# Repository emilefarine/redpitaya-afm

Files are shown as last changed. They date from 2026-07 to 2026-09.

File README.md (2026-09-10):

# Open-Source Zynq-Based AFM Acquisition System

An open, low-cost acquisition instrument for Atomic Force Microscopy (AFM), built around the
[Red Pitaya STEMlab 125-14](https://redpitaya.com/) (Xilinx Zynq-7010 SoC) and delivered as a
self-contained 19-inch rack unit. It replaces the closed, expensive and proprietary acquisition
boards typically used in AFM setups with a fully inspectable and extensible signal chain.

The instrument generates an excitation signal, conditions it through a custom analog board,
drives the AFM, acquires the cantilever response, and processes it (FFT, peak detection,
lock-in detection) entirely on the device. Results are exposed over the network through an
SCPI-inspired protocol and can be driven from Python, LabVIEW, MATLAB or any TCP client.

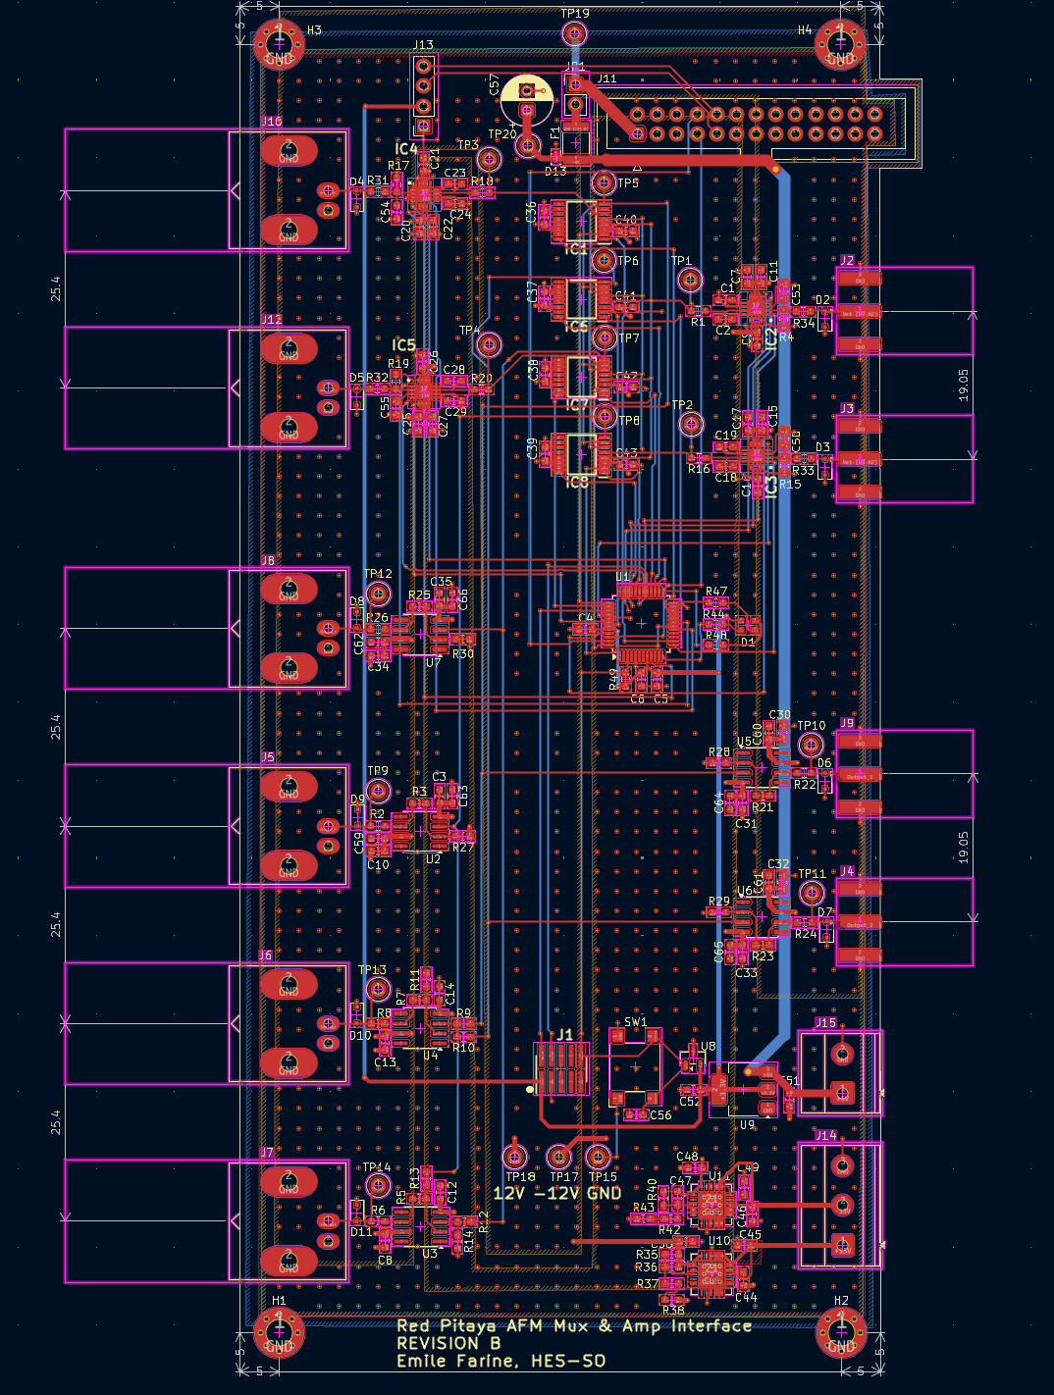
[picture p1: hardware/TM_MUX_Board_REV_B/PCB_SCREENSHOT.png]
MUX board


## Architecture

The system is organised in four layers:

| Layer | Description | Location |
|---|---|---|
| **FPGA datapath** | Custom programmable-logic design on the Zynq: excitation generation and acquisition around a single shared BRAM, with adaptive decimation | [`fpga/`](fpga/) |
| **Analog board** | Custom conditioning board: programmable gain (×1/8 to ×16), input multiplexer, ±10 V range, analog sum/difference outputs, LPC1114 control microcontroller, OLED IP display | [`hardware/`](hardware/), [`ElectronicBoard/`](ElectronicBoard/) |
| **Embedded C++ server** | Single-client TCP server running on the Red Pitaya's Linux, exposing an SCPI-inspired command language over the network | [`cpp/`](cpp/) |
| **Python clients** | Client library, interactive CLI, PyQt6 desktop GUI with routing schematic dialog, and deployment tooling | [`python/`](python/) |

Two measurement modes are available: a **broadband sinc** that captures a whole spectrum in a
few milliseconds, and a **lock-in sweep** that resolves narrow resonances.

### Repository layout

```
cpp/                 Embedded C++ server + signal processing (build & run on the Red Pitaya)
  Hardware/          Hardware abstraction: FPGA register access, board UART, SSD1306 OLED
  Server/            TCP server, SCPI command handler, protocol
  SignalProcessing/  Signal generation, FFT (FFTW3), resonance analysis
  Tools/             oled-ip helper + systemd service
  tests/             Host-side unit tests (run on the dev PC, no Red Pitaya needed)
python/              Client library, CLI, GUI (with routing schematic dialog) and deployment
fpga/
  rtl/               SystemVerilog / VHDL sources for the custom datapath
  bitfiles/          Prebuilt bitstream (flash without rebuilding in Vivado)
ElectronicBoard/
  src/               LPC1114 firmware for the analog board (MUX + gain control)
hardware/
  TM_MUX_Board_REV_B/  KiCad 10 project: schematics, PCB, 3D model, interactive BOM
```

## Requirements

### Hardware
- Red Pitaya STEMlab 125-14 (Zynq-7010)
- Custom analog MUX board (optional; design in [`hardware/`](hardware/)). Without it the
  server runs in Red Pitaya-only mode and the `BOARD:*` commands are unavailable.

### Software
- **Client PC:** Python **3.10+** (developed on 3.13)
- **On the Red Pitaya:** `g++` (C++17), FFTW3 single precision (`libfftw3f`), Red Pitaya
  libraries (`librp`, `librp-hw`, `librp-hw-calib`, `librp-hw-profiles`), all present on
  the stock Red Pitaya OS 2.0+ image
- **FPGA rebuilds only:** Xilinx Vivado/Vitis (a prebuilt bitstream is shipped, so this is
  optional)
- **Board firmware only:** MCUXpresso IDE + a J-Link EDU mini

## Installation

```bash
git clone https://github.com/emilefarine/redpitaya-afm 
cd redpitaya-afm
python -m venv .venv
# Windows:  .venv\Scripts\activate.bat
# Linux/macOS:  source .venv/bin/activate
pip install -r python/requirements.txt
```

All scripts that connect to the board accept `--host <ip>` (or the `RP_HOST` environment
variable). SSH credentials default to the Red Pitaya factory login `root` / `root` and can be
overridden with `--user` / `--password` (or `RP_USER` / `RP_PASSWORD`).

## Usage

### 1. Flash the FPGA bitstream

A prebuilt bitstream is included, so you do not need Vivado:

```bash
python python/rp_deploy.py --host 192.168.1.100 --deploy
python python/rp_deploy.py --host 192.168.1.100 --status   # expect: FPGA state operating
```

By default the newest `fpga/bitfiles/*.bit.bin` is used; pass `--bitfile <path>` to select
another. A raw `.bit` (from a local Vivado build) is converted automatically with `bootgen`
(point to it with `--bootgen` / the `BOOTGEN` env var, or let the script scan a local Vitis
install).

### 2. Build and deploy the C++ server

The C++ code is compiled **on the Red Pitaya** (not cross-compiled). `rp_deploy.py` mirrors
the sources over SSH, then build with `make`:

```bash
python python/rp_deploy.py --host 192.168.1.100 --cpp      # sync sources to the board

# then over SSH on the Red Pitaya, from the synced cpp/ directory:
make server        # build the AFM SCPI server
./out/afm_server   # run it (listens on TCP 5025)
```

Other `make` targets: `make all` (server + tools), `make tools`.

Host-side unit tests run on the dev PC without a Red Pitaya. Shell: the MSYS2 UCRT64
shell on Windows (install `mingw-w64-ucrt-x86_64-gtest` and `mingw-w64-ucrt-x86_64-fftw`
via pacman) or any POSIX shell on Linux (`apt install libgtest-dev libgmock-dev
libfftw3-dev`), plus `pip install gcovr` for coverage. From `cpp/`:

```bash
make test_host      # build and run the unit tests
make coverage       # unit tests + HTML report at out/host/coverage/index.html
```

### 3. Red Pitaya-only operation (no analog board)

The custom analog board is optional. To run measurements with only a Red Pitaya, start the
server with `--no-board`, the electronic board is then never probed and every `BOARD:*`
command is rejected with `ERR_HARDWARE: Electronic board disabled (RP-only mode)`:

```bash
./out/afm_server --no-board
```

Connect the cantilever signal directly to **IN1**, the only input acquired by the FPGA
datapath. `MEASURE:SINC` and `MEASURE:SWEEP` work exactly as with the board, mux routing
and programmable gain are unavailable. Query the active mode with `SYSTEM:MODE?` (`FULL`
or `RP_ONLY`); `SYSTEM:STATUS?` also reports `MODE=`. The GUI disables the board panel and
the routing schematic automatically in RP-only mode.

### 4. Connect a client

Interactive CLI:

```bash
python python/afm_cli.py 192.168.1.100
```

Desktop GUI (PyQt6, real-time magnitude/phase plots):

```bash
python python/afm_gui.py
```

The GUI has an "Open Routing Schematic" button showing the live 4x4 crossbar
routing and PGA gains (read from `BOARD:STATUS?`); the same dialog runs
standalone without hardware for preview:

```bash
python python/afm_schematic.py
```

Python library:

```python
from afm_client import AFMClient

with AFMClient("192.168.1.100") as client:
    client.init()
    spectrum = client.measure_sinc(center_kHz=1000, bandwidth_kHz=200)
    peak = spectrum.freq_kHz[spectrum.magnitude.argmax()]
    print(f"Peak at {peak:.1f} kHz")

    sweep = client.measure_sweep(center_kHz=1000, range_kHz=100, step_kHz=0.5)
```

## SCPI protocol

The server speaks an SCPI-inspired ASCII protocol over **TCP port 5025**. Commands are
case-insensitive, colon-separated, `?`-suffixed for queries, with comma-separated arguments;
every line ends with `\n`. Responses are a single line: `OK [data]` or `ERR_<CODE>: <message>`.

| Command | Description |
|---|---|
| `*IDN?` / `*RST` / `*OPC?` | IEEE 488.2 common commands |
| `SYSTEM:INIT` / `SYSTEM:DEINIT` / `SYSTEM:STATUS?` | Hardware lifecycle and status |
| `SYSTEM:PING` / `SYSTEM:VERSION?` / `SYSTEM:SHUTDOWN` | Connectivity check, server version, server shutdown |
| `SYSTEM:MODE?` | Operating mode: `FULL` or `RP_ONLY` (board disabled with `--no-board`) |
| `BOARD:MUX:ROUTE <out>,<in>` | Route input to output (channels 1-4) |
| `BOARD:MUX:DISCONNECT <out>` | Disconnect a multiplexer output |
| `BOARD:GAIN <ch>,<idx>` | Set programmable gain (idx 0-7 → ×1/8 … ×16) |
| `BOARD:STATUS?` / `BOARD:RESET` | Query board routing/gains, reset board to defaults |
| `MEASURE:SINC <center_kHz>,<bw_kHz>[,<samples>,<dec>,<amp>]` | Broadband sinc + FFT |
| `MEASURE:SWEEP <center_kHz>,<range_kHz>[,<step_kHz>,<dec>,<amp>]` | Lock-in frequency sweep |

`MEASURE:*` return a multi-line spectrum: a header `OK DATA <N> <BYTES>` followed by `N` rows of
`freq_kHz,magnitude,phase_rad`. `<BYTES>` is the exact size of the payload that follows the
header line, so a client can read it in one shot instead of scanning for newlines.

## MUX board firmware

The analog board is controlled by an on-board **LPC1114** microcontroller (MUX routing,
programmable gain, OLED IP display). Firmware sources are in [`ElectronicBoard/src/`](ElectronicBoard/src/).

To build and flash with **MCUXpresso IDE**:

1. Create a new C++ project for the LPC1114/LPC1125 target (the sources include the
   `cr_startup_lpc11xx` startup and `crp.c` code-read-protection files).
2. Import the contents of `ElectronicBoard/src/` into the project's source folder.
3. Build, then flash to the board over SWD using a **J-Link** debug probe (Debug / Program).

## Hardware design

The analog MUX board (REV B) is designed in **KiCad 10**, under
[`hardware/TM_MUX_Board_REV_B/`](hardware/TM_MUX_Board_REV_B/):

- Schematics: open `TM_MUX_Board_REV_B.kicad_pro`, or read the exported PDFs
- PCB layout: `TM_MUX_Board_REV_B.kicad_pcb`
- 3D model: `TM_MUX_Board_REV_B.step`
- Interactive BOM: `bom/ibom.html` (open in a browser)

## License

Released under the [MIT License](LICENSE).

Developed as a Master's thesis, *"Design and Implementation of an Open-Source Zynq-Based
Synchronous Acquisition System for Atomic Force Microscopy"*, by Emile Farine at the HES-SO
Master of Science in Engineering (hepia / MSE), in collaboration with the DQMP, University of
Geneva.

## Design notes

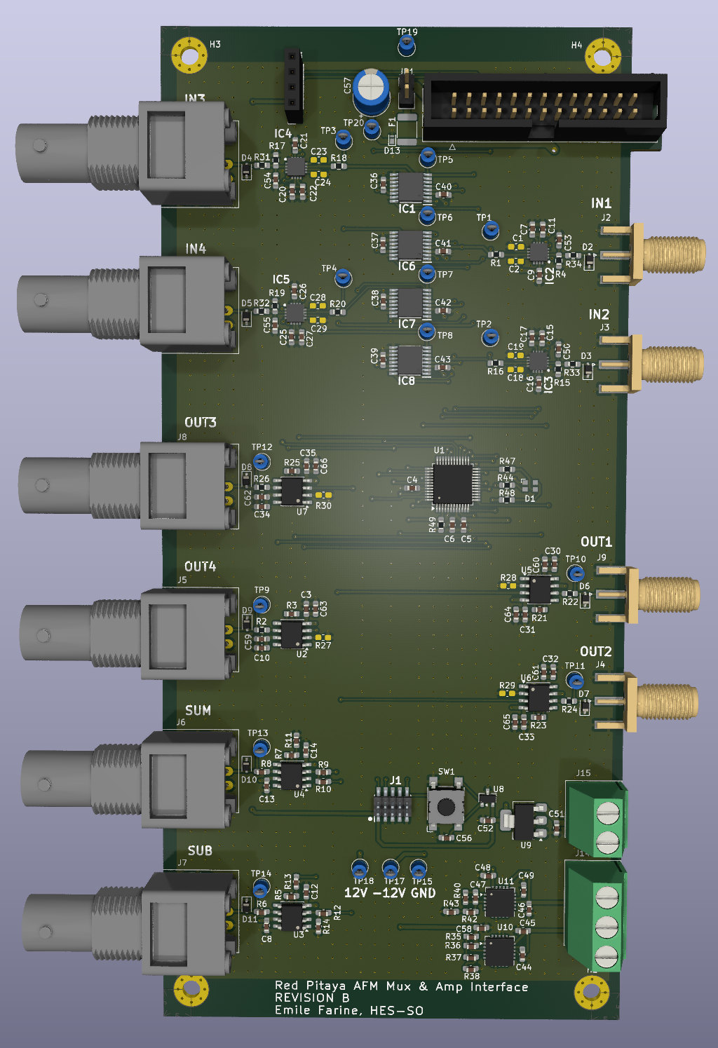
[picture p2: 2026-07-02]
hardware/TM_MUX_Board_REV_B/TM_MUX_Board_REV_B.png

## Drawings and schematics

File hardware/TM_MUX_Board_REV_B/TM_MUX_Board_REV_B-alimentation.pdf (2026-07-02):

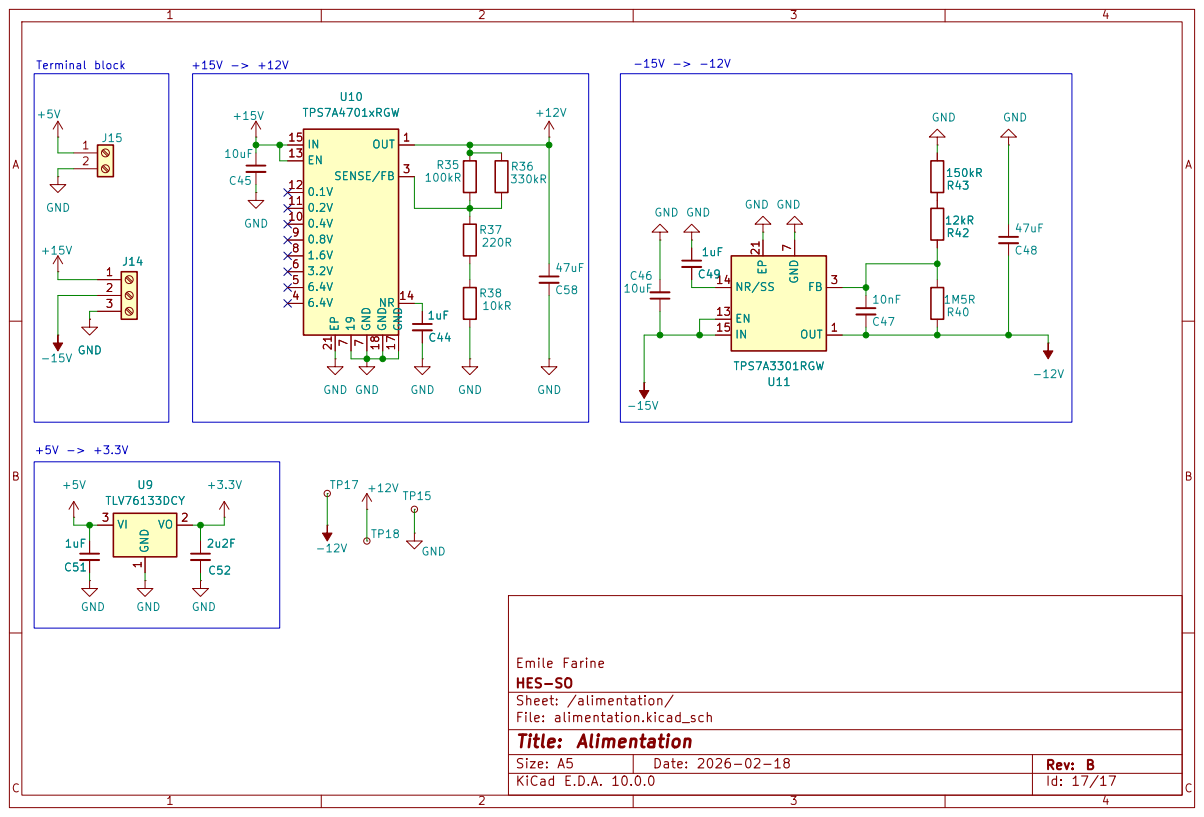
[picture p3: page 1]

Size: A5 | Rev: B | C Date: 2026-02-18 KiCad E.D.A. 10.0.0

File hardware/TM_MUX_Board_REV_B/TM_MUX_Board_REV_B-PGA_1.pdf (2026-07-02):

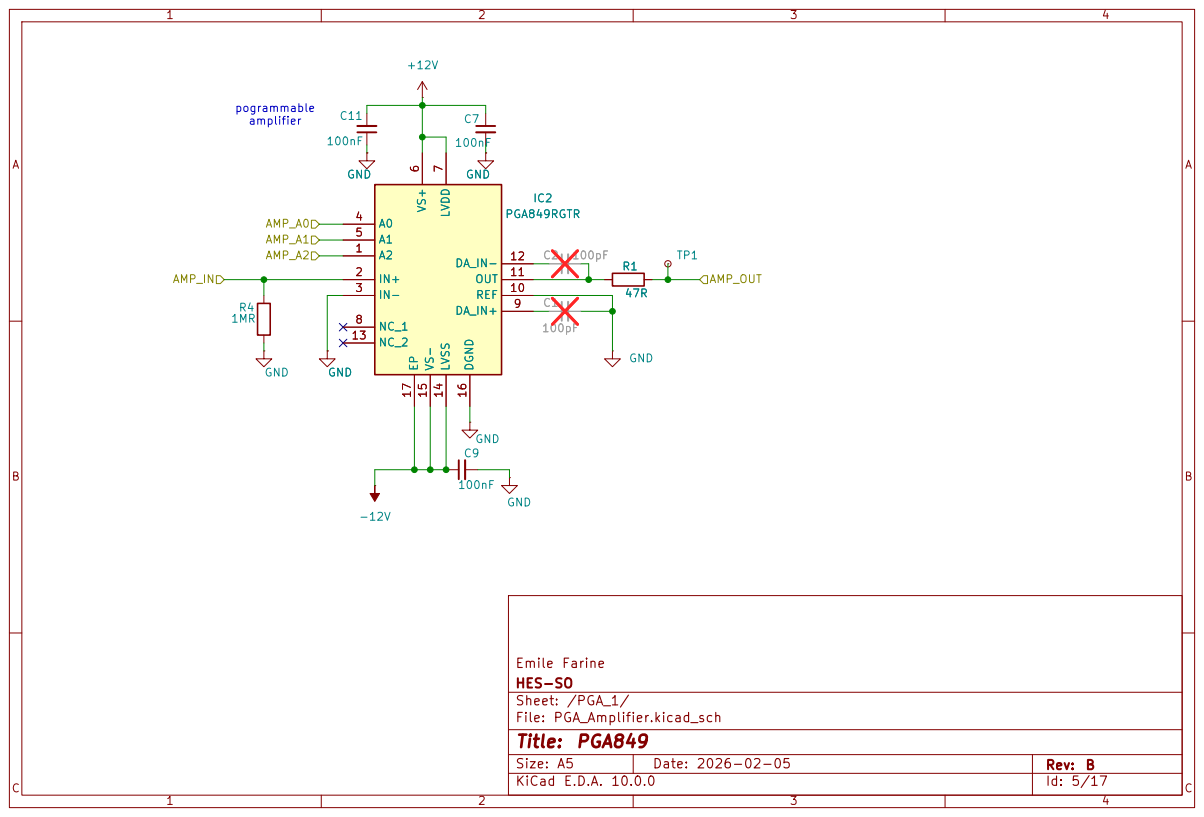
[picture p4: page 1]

7 NC_1 8 DA_IN+ 9 REF 10 OUT 11 DA_IN- 12 NC_2 13 LVSS 14 VS- 15 DGND 16 EP 17

7 NC_1 8 DA_IN+ 9 REF 10 OUT 11 DA_IN- 12 NC_2 13 LVSS 14 VS- 15 DGND 16 EP 17 C2 100pF

Size: A5 | Rev: B | C Date: 2026-02-05 KiCad E.D.A. 10.0.0

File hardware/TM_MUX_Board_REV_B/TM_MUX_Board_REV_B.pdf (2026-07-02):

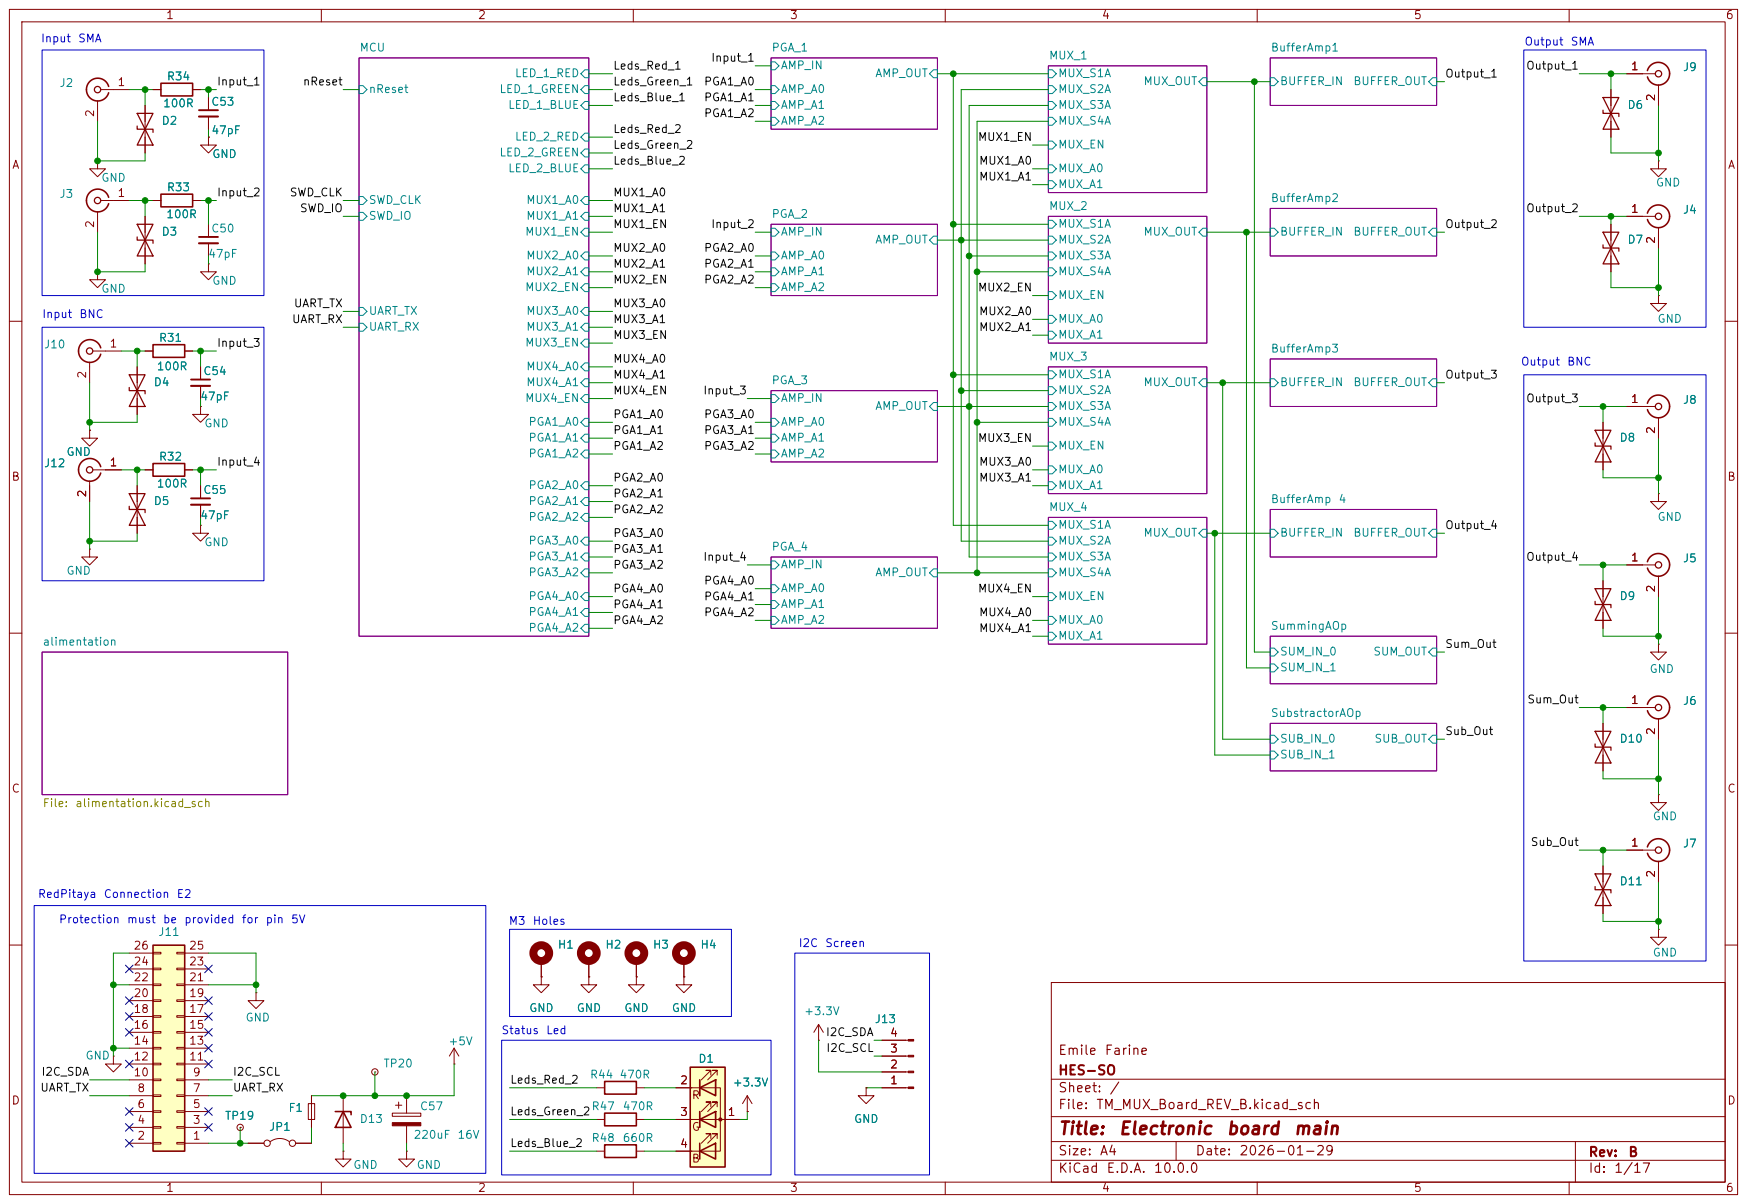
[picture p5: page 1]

Emile Farine
HES-SO
Sheet: /
D Date: 2026-01-29 KiCad E.D.A. 10.0.0
File: TM_MUX_Board_REV_B.kicad_sch
Title: Electronic board main

Size: A4 | Rev: B

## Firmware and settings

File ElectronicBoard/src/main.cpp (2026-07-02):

/*
 * main.cpp
 * Main application for LPC1114/LPC1125 Electronic Board
 *
 * Analog Signal Multiplexer with Variable Gain Amplification
 * - 4 analog inputs with variable gain (x1/4 to x8)
 * - 4 multiplexed outputs
 * - Addition output (OUT1 + OUT2)
 * - Subtraction output (OUT3 - OUT4)
 * - UART command interface for Red Pitaya control
 */

#include "chip.h"
#include "command_parser.h"
#include "mux_control.h"
#include "pin_init.h"
#include "uart.h"
#include <cr_section_macros.h>
#include <cstdint>

const uint32_t OscRateIn = 12000000; // 12 MHz
const uint32_t ExtRateIn = 0;        // No external clock input

/*****************************************************************************
 * Main application
 *****************************************************************************/
int main(void) {
  // Initialize system clock
  SystemCoreClockUpdate();

  // Initialize IOCON clock (needed for pin mux)
  Chip_Clock_EnablePeriphClock(SYSCON_CLOCK_IOCON);

  // Initialize GPIO
  Chip_GPIO_Init(LPC_GPIO);

  // Initialize all GPIO pins
  GPIO_InitAllPins();

  // Initialize UART for communication
  UART_Init();

  // Initialize multiplexer control
  MUX_Init();

  // Initialize command parser
  CMD_Init();

  // Send startup message
  UART_SendString("\r\n");
  UART_SendString("Baud: ");
  UART_SendInt(UART_BAUD_RATE);
  UART_SendString("\r\nClock: ");
  UART_SendUInt(SystemCoreClock);
  UART_SendString(" Hz\r\n");
  UART_SendString("\r\nType HELP for commands\r\n");
  UART_SendString("> ");

  // LED blink counter for heartbeat
  volatile uint32_t blinkCounter = 0;
  bool ledState = false;

  // Main loop - command processing
  while (1) {
    // Check for incoming UART data (non-blocking)
    char c;
    if (UART_ReadChar(&c)) {
      CMD_ProcessChar(c);

      // Execute command if ready
      if (CMD_IsReady()) {
        CMD_Execute();
        UART_SendString("> ");
      }
    }

    // Heartbeat LED: 50ms ON, 2s OFF
    blinkCounter++;
    if (ledState) {
      if (blinkCounter >= 10000) {
        blinkCounter = 0;
        ledState = false;
        Chip_GPIO_SetPinState(LPC_GPIO, 2, 8, true);
        Chip_GPIO_SetPinState(LPC_GPIO, 2, 9, true);
        Chip_GPIO_SetPinState(LPC_GPIO, 2, 10, true);
      }
    } else {
      if (blinkCounter >= 400000) {
        blinkCounter = 0;
        ledState = true;
        Chip_GPIO_SetPinState(LPC_GPIO, 2, 8, false);
        Chip_GPIO_SetPinState(LPC_GPIO, 2, 9, false);
        Chip_GPIO_SetPinState(LPC_GPIO, 2, 10, false);
      }
    }
  }

  return 0;
}

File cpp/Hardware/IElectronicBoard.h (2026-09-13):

#pragma once

#include <array>
#include <cstdint>
#include <string>

/**
 * @brief Gain settings for PGA849 amplifier
 */
enum class GainSetting : uint8_t
{
  GAIN_1_8 = 0,
  GAIN_1_4 = 1,
  GAIN_1_2 = 2,
  GAIN_1 = 3,
  GAIN_2 = 4,
  GAIN_4 = 5,
  GAIN_8 = 6,
  GAIN_16 = 7
};

/**
 * @brief Interface for the LPC1114 electronic board (MUX routing + gain control)
 *
 * Wire protocol (implemented by ElectronicBoardUART):
 *   Commands are ASCII text terminated by '\n' (LF)
 *   Responses: "OK\r\n" on success, "ERR:<message>\r\n" on error
 *
 * The C++ API uses 0-indexed channel parameters (0-3); the translation to
 * 1-based wire format matching board connector labels is done internally.
 */
class IElectronicBoard
{
public:
  virtual ~IElectronicBoard() = default;

  // Number of MUX channels (declared before use in member signatures)
  static constexpr uint8_t NUM_CHANNELS = 4;
  static constexpr uint8_t DISCONNECTED = 0xFF;

  virtual bool initialize() = 0;
  virtual void close() = 0;
  virtual bool isConnected() const = 0;

  /**
   * @brief Route an input channel to an output channel
   * @param output Output channel (0-3, maps to board connector OUT1-OUT4)
   * @param input Input channel (0-3, maps to board connector IN1-IN4)
   */
  virtual bool setMuxRoute(uint8_t output, uint8_t input) = 0;

  /**
   * @brief Disconnect a multiplexer output
   * @param output Output channel (0-3, maps to board connector OUT1-OUT4)
   */
  virtual bool disconnectMux(uint8_t output) = 0;

  /**
   * @brief Set amplifier gain for a channel
   * @param channel Input channel (0-3, maps to board connector IN1-IN4)
   */
  virtual bool setGain(uint8_t channel, GainSetting gain) = 0;

  /**
   * @brief Request status from the board
   * @param statusOut String to receive status output
   */
  virtual bool getStatus(std::string& statusOut) = 0;

  /**
   * @brief Query the gain of every input channel
   *
   * Structured alternative to parsing the human-readable STATUS text in
   * upper layers. validOut[i] is false when the gain of channel i could not
   * be recovered; callers must treat invalid channels conservatively.
   *
   * @param gainsOut Receives the gain of each channel (indexed 0-3)
   * @param validOut Receives whether each gain was successfully read
   * @return true on transport success (individual channels may still be invalid)
   */
  virtual bool queryGains(std::array<GainSetting, NUM_CHANNELS>& gainsOut,
                          std::array<bool, NUM_CHANNELS>& validOut) = 0;

  /** @brief Reset board to defaults (all outputs disconnected, all gains set to 1) */
  virtual bool reset() = 0;

  /** @brief Get last error message */
  virtual const std::string& getLastError() const = 0;

  /**
   * @brief Get gain value as a human-readable string
   * @param gain Gain setting
   * @return String representation (e.g., "1/4", "1", "8")
   */
  static const char* gainToString(GainSetting gain)
  {
    const uint8_t raw = static_cast<uint8_t>(gain);
    return raw <= MAX_GAIN_INDEX ? c_GainTable[raw].label : "?";
  }

  /**
   * @brief Get the numeric gain factor of a setting (x1/8 .. x16)
   *
   * Unknown enum values fall back to the maximum gain (x16): the ADC
   * overdrive estimate must degrade to the most conservative assumption.
   * @param gain Gain setting
   * @return Voltage gain factor (0.125 .. 16)
   */
  static float gainFactor(GainSetting gain)
  {
    return c_GainTable[gainToIndex(gain)].factor;
  }

  /**
   * @brief Map a board gain label ("1/8".."16") to a gain setting
   * @return true when the label is recognized
   */
  static bool gainFromLabel(const std::string& label, GainSetting& settingOut)
  {
    for (const auto& entry : c_GainTable)
    {
      if (label == entry.label)
      {
        settingOut = entry.setting;
        return true;
      }
    }
    return false;
  }

  /**
   * @brief Map a gain setting to its SCPI gain index (0-7)
   */
  static uint8_t gainToIndex(GainSetting gain)
  {
    const uint8_t index = static_cast<uint8_t>(gain);
    return index > MAX_GAIN_INDEX ? MAX_GAIN_INDEX : index;
  }

  /**
   * @brief Map a SCPI gain index (0-7) to a gain setting
   *
   * Out-of-range indices degrade to the maximum gain (fail-safe).
   */
  static GainSetting gainFromIndex(uint8_t index)
  {
    return index > MAX_GAIN_INDEX ? GainSetting::GAIN_16 : static_cast<GainSetting>(index);
  }

  /** Highest valid SCPI gain index (GainSetting spans 0..7 in SCPI order) */
  static constexpr uint8_t MAX_GAIN_INDEX = 7;
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

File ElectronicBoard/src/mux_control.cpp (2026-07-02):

/*
 * mux_control.cpp
 * Multiplexer and Amplifier control implementation
 *
 * Hardware Configuration:
 * - ADG1409YRUZ: 4:1 analog multiplexer, controlled by A0, A1, EN pins
 * - PGA855: Variable gain amplifier, controlled by A0, A1, A2 pins
 *
 *  Created on: 26 Nov 2025
 */

#include "mux_control.h"
#include "uart.h"

// Pin Definitions - Multiplexers (ADG1409)

// Multiplexer 1 - Output 1 (0-indexed internally: 0)
#define MUX1_A0_PORT 0
#define MUX1_A0_PIN 3
#define MUX1_A1_PORT 0
#define MUX1_A1_PIN 6
#define MUX1_EN_PORT 3
#define MUX1_EN_PIN 1

// Multiplexer 2 - Output 2 (0-indexed internally: 1)
#define MUX2_A0_PORT 0
#define MUX2_A0_PIN 7
#define MUX2_A1_PORT 0
#define MUX2_A1_PIN 8
#define MUX2_EN_PORT 3
#define MUX2_EN_PIN 2

// Multiplexer 3 - Output 3 (0-indexed internally: 2)
#define MUX3_A0_PORT 0
#define MUX3_A0_PIN 9
#define MUX3_A1_PORT 2
#define MUX3_A1_PIN 3
#define MUX3_EN_PORT 3
#define MUX3_EN_PIN 3

// Multiplexer 4 - Output 4 (0-indexed internally: 3)
#define MUX4_A0_PORT 0
#define MUX4_A0_PIN 11
#define MUX4_A1_PORT 1
#define MUX4_A1_PIN 0
#define MUX4_EN_PORT 3
#define MUX4_EN_PIN 4

// Pin Definitions - Variable Gain Amplifiers (PGA849)

// Amplifier 1 - Input 1 (0-indexed internally: 0)
#define AMP1_A0_PORT 1
#define AMP1_A0_PIN 1
#define AMP1_A1_PORT 1
#define AMP1_A1_PIN 2
#define AMP1_A2_PORT 2
#define AMP1_A2_PIN 11

// Amplifier 2 - Input 2 (0-indexed internally: 1)
#define AMP2_A0_PORT 1
#define AMP2_A0_PIN 4
#define AMP2_A1_PORT 1
#define AMP2_A1_PIN 5
#define AMP2_A2_PORT 2
#define AMP2_A2_PIN 1

// Amplifier 3 - Input 3 (0-indexed internally: 2)
#define AMP3_A0_PORT 2
#define AMP3_A0_PIN 2
#define AMP3_A1_PORT 1
#define AMP3_A1_PIN 8
#define AMP3_A2_PORT 1
#define AMP3_A2_PIN 9

// Amplifier 4 - Input 4 (0-indexed internally: 3)
#define AMP4_A0_PORT 1
#define AMP4_A0_PIN 10
#define AMP4_A1_PORT 1
#define AMP4_A1_PIN 11
#define AMP4_A2_PORT 2
#define AMP4_A2_PIN 4

/*****************************************************************************
 * Internal State
 *****************************************************************************/

// Current routing: muxRouting[output] = input (or MUX_DISCONNECTED)
static uint8_t muxRouting[MUX_NUM_CHANNELS];

// Current gain settings for each input channel
static GainSetting_t ampGains[MUX_NUM_CHANNELS];

// Gain strings for display
static const char *gainStrings[GAIN_COUNT] = {"1/8", "1/4", "1/2", "1",
                                              "2",   "4",   "8",   "16"};

/*****************************************************************************
 * Pin Mapping Tables
 *****************************************************************************/

typedef struct {
  uint8_t a0Port, a0Pin;
  uint8_t a1Port, a1Pin;
  uint8_t enPort, enPin;
} MuxPins_t;

typedef struct {
  uint8_t a0Port, a0Pin;
  uint8_t a1Port, a1Pin;
  uint8_t a2Port, a2Pin;
} AmpPins_t;

static const MuxPins_t muxPins[MUX_NUM_CHANNELS] = {
    {MUX1_A0_PORT, MUX1_A0_PIN, MUX1_A1_PORT, MUX1_A1_PIN, MUX1_EN_PORT,
     MUX1_EN_PIN},
    {MUX2_A0_PORT, MUX2_A0_PIN, MUX2_A1_PORT, MUX2_A1_PIN, MUX2_EN_PORT,
     MUX2_EN_PIN},
    {MUX3_A0_PORT, MUX3_A0_PIN, MUX3_A1_PORT, MUX3_A1_PIN, MUX3_EN_PORT,
     MUX3_EN_PIN},
    {MUX4_A0_PORT, MUX4_A0_PIN, MUX4_A1_PORT, MUX4_A1_PIN, MUX4_EN_PORT,
     MUX4_EN_PIN},
};

static const AmpPins_t ampPins[MUX_NUM_CHANNELS] = {
    {AMP1_A0_PORT, AMP1_A0_PIN, AMP1_A1_PORT, AMP1_A1_PIN, AMP1_A2_PORT,
     AMP1_A2_PIN},
    {AMP2_A0_PORT, AMP2_A0_PIN, AMP2_A1_PORT, AMP2_A1_PIN, AMP2_A2_PORT,
     AMP2_A2_PIN},
    {AMP3_A0_PORT, AMP3_A0_PIN, AMP3_A1_PORT, AMP3_A1_PIN, AMP3_A2_PORT,
     AMP3_A2_PIN},
    {AMP4_A0_PORT, AMP4_A0_PIN, AMP4_A1_PORT, AMP4_A1_PIN, AMP4_A2_PORT,
     AMP4_A2_PIN},
};

/**
 * @brief Set GPIO pin state
 */
static inline void SetPin(uint8_t port, uint8_t pin, bool state) {
  Chip_GPIO_SetPinState(LPC_GPIO, port, pin, state);
}

/**
 * @brief Apply multiplexer hardware settings
 * @param muxIndex Multiplexer index (0-3)
 */
static void MUX_ApplyHardware(uint8_t muxIndex) {
  const MuxPins_t *pins = &muxPins[muxIndex];
  uint8_t input = muxRouting[muxIndex];

  if (input == MUX_DISCONNECTED || input >= MUX_NUM_INPUTS) {
    // Disable multiplexer (EN = LOW)
    SetPin(pins->enPort, pins->enPin, false);
    SetPin(pins->a0Port, pins->a0Pin, false);
    SetPin(pins->a1Port, pins->a1Pin, false);
  } else {
    // Set input selection (A0, A1)
    SetPin(pins->a0Port, pins->a0Pin, (input & 0x01) != 0);
    SetPin(pins->a1Port, pins->a1Pin, (input & 0x02) != 0);
    // Enable multiplexer (EN = HIGH)
    SetPin(pins->enPort, pins->enPin, true);
  }
}

/**
 * @brief Apply amplifier hardware settings
 * @param ampIndex Amplifier index (0-3)
 */
static void AMP_ApplyHardware(uint8_t ampIndex) {
  const AmpPins_t *pins = &ampPins[ampIndex];
  uint8_t gain = (uint8_t)ampGains[ampIndex];

  // Set gain selection (A0, A1, A2)
  SetPin(pins->a0Port, pins->a0Pin, (gain & 0x01) != 0);
  SetPin(pins->a1Port, pins->a1Pin, (gain & 0x02) != 0);
  SetPin(pins->a2Port, pins->a2Pin, (gain & 0x04) != 0);
}

/*****************************************************************************
 * Public Functions
 *****************************************************************************/

void MUX_Init(void) {
  // Initialize all outputs as disconnected
  for (uint8_t i = 0; i < MUX_NUM_CHANNELS; i++) {
    muxRouting[i] = MUX_DISCONNECTED;
    MUX_ApplyHardware(i);
  }

  // Initialize all gains to 1 (unity gain)
  for (uint8_t i = 0; i < MUX_NUM_CHANNELS; i++) {
    ampGains[i] = GAIN_1;
    AMP_ApplyHardware(i);
  }
}

bool MUX_SetRoute(uint8_t output, uint8_t input) {
  // Validate output
  if (output >= MUX_NUM_CHANNELS) {
    return false;
  }

  // Handle disconnection
  if (input == MUX_DISCONNECTED) {
    MUX_Disconnect(output);
    return true;
  }

  // Validate input
  if (input >= MUX_NUM_INPUTS) {
    return false;
  }

  // Set the routing (same input can be routed to multiple outputs)
  muxRouting[output] = input;
  MUX_ApplyHardware(output);

  return true;
}

uint8_t MUX_GetRoute(uint8_t output) {
  if (output >= MUX_NUM_CHANNELS) {
    return MUX_DISCONNECTED;
  }
  return muxRouting[output];
}

uint8_t MUX_GetInputUsage(uint8_t input) {
  if (input >= MUX_NUM_INPUTS) {
    return MUX_DISCONNECTED;
  }

  for (uint8_t i = 0; i < MUX_NUM_CHANNELS; i++) {
    if (muxRouting[i] == input) {
      return i;
    }
  }

  return MUX_DISCONNECTED;
}

void MUX_Disconnect(uint8_t output) {
  if (output < MUX_NUM_CHANNELS) {
    muxRouting[output] = MUX_DISCONNECTED;
    MUX_ApplyHardware(output);
  }
}

void MUX_DisconnectAll(void) {
  for (uint8_t i = 0; i < MUX_NUM_CHANNELS; i++) {
    muxRouting[i] = MUX_DISCONNECTED;
    MUX_ApplyHardware(i);
  }
}

bool AMP_SetGain(uint8_t channel, GainSetting_t gain) {
  if (channel >= MUX_NUM_CHANNELS || gain >= GAIN_COUNT) {
    return false;
  }

  ampGains[channel] = gain;
  AMP_ApplyHardware(channel);

  return true;
}
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

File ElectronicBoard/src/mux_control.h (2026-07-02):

/*
 * mux_control.h
 * Multiplexer and Amplifier control for the Electronic Board
 *
 * Hardware: ADG1409YRUZ multiplexers, PGA855 variable gain amplifiers
 *
 *  Created on: 26 Nov 2025
 */

#ifndef MUX_CONTROL_H_
#define MUX_CONTROL_H_

#include "chip.h"
#include <cstdint>

#ifdef __cplusplus
extern "C" {
#endif

/*****************************************************************************
 * Constants
 *****************************************************************************/

#define MUX_NUM_CHANNELS 4    // 4 multiplexer outputs
#define MUX_NUM_INPUTS 4      // 4 possible inputs per mux
#define MUX_DISCONNECTED 0xFF // Value for disconnected output

// Gain codes for PGA849 (3-bit: A2, A1, A0)
typedef enum {
  GAIN_1_8 = 0,
  GAIN_1_4 = 1,
  GAIN_1_2 = 2,
  GAIN_1 = 3,
  GAIN_2 = 4,
  GAIN_4 = 5,
  GAIN_8 = 6,
  GAIN_16 = 7,
  GAIN_COUNT = 8
} GainSetting_t;

/**
 * @brief Initialize multiplexer control module
 * Sets all outputs to disconnected and gains to 1
 */
void MUX_Init(void);

/**
 * @brief Set multiplexer routing
 * @param output Output channel (0-3, maps to board connector OUT1-OUT4)
 * @param input Input channel (0-3, maps to board connector IN1-IN4) or MUX_DISCONNECTED to disable
 * @return true if successful, false if invalid parameters or input already used
 */
bool MUX_SetRoute(uint8_t output, uint8_t input);

/**
 * @brief Get current multiplexer routing
 * @param output Output channel (0-3, maps to board connector OUT1-OUT4)
 * @return Input channel (0-3) or MUX_DISCONNECTED if disabled
 */
uint8_t MUX_GetRoute(uint8_t output);

/**
 * @brief Check if an input is already routed to an output
 * @param input Input channel (0-3, maps to board connector IN1-IN4)
 * @return Output channel (0-3) if routed, or MUX_DISCONNECTED if not used
 */
uint8_t MUX_GetInputUsage(uint8_t input);

/**
 * @brief Disconnect a multiplexer output
 * @param output Output channel (0-3, maps to board connector OUT1-OUT4)
 */
void MUX_Disconnect(uint8_t output);

/**
 * @brief Disconnect all multiplexer outputs
 */
void MUX_DisconnectAll(void);

/**
 * @brief Set amplifier gain for an input channel
 * @param channel Input channel (0-3, maps to board connector IN1-IN4)
 * @param gain Gain setting (GAIN_1_8 to GAIN_16)
 * @return true if successful, false if invalid parameters
 */
bool AMP_SetGain(uint8_t channel, GainSetting_t gain);

/**
 * @brief Get current amplifier gain for a channel
 * @param channel Input channel (0-3, maps to board connector IN1-IN4)
 * @return Current gain setting
 */
GainSetting_t AMP_GetGain(uint8_t channel);

/**
 * @brief Get gain value as a string (for display/debug)
 * @param gain Gain setting
 * @return String representation (e.g., "1/4", "2", "8")
 */
const char *AMP_GainToString(GainSetting_t gain);

/**
 * @brief Print current configuration via UART
 */
void MUX_PrintStatus(void);

#ifdef __cplusplus
}
#endif

#endif /* MUX_CONTROL_H_ */

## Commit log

2026-07-02 Initial project commit
    [MCU.kicad_sch, Mux_Module.kicad_sch, Output_Buffer.kicad_sch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]
2026-09-09 ADD: portable DAC/ADC codec header (DacCodec.h)
2026-09-09 REM(calib): strip loopback calibration from public tree
2026-09-09 ADD(python): routing schematic dialog, board state client, sweep phase fix
2026-09-09 MOD(docs): refresh README (paths, tests, schematic, SCPI); fix OLED service path
2026-09-10 FIX(protocol): reject non-finite float arguments
    [Protocol.h, test_command_handler.cpp]
2026-09-10 FIX(server): validate frequency limits and sweep point count
    [CommandHandler.cpp, Protocol.h, test_command_handler.cpp]
2026-09-10 FIX(server): reset measurement on sweep timeout
    [CommandHandler.cpp, test_command_handler.cpp]
2026-09-10 FIX(signal): skip windowing for single-sample signals
2026-09-10 FIX(board): cap UART receive buffer
    [ElectronicBoardUART.cpp]
2026-09-10 FIX(server): pin fpgautil lookup to absolute paths
2026-09-10 FIX(server): stop sweep at range end and always clear busy state
    [CommandHandler.cpp, test_command_handler.cpp]
2026-09-10 FIX(board): do not drop terminated UART line on overflow
    [ElectronicBoardUART.cpp]
2026-09-10 TEST(server): add command handler edge case tests
2026-09-10 FIX(analyzer): clamp bin conversion and bound peak search
2026-09-10 FIX(signal): reject invalid generator parameters
    [CommandHandler.cpp, test_command_handler.cpp]
2026-09-10 FIX(hardware): handle non-finite DAC voltages
    [DacCodec.h, test_dac_codec.cpp]
2026-09-10 FIX(server): preserve empty SCPI argument tokens
    [Protocol.h, test_command_handler.cpp]
2026-09-10 REF(board): extract BoardProtocol from ElectronicBoardUART
2026-09-10 FIX(client): harden parsing, locking and connection lifecycle
    - Bound response lines, spectrum rows and payload bytes; reject
    malformed or oversized headers with AFMProtocolError instead of
    leaking ValueError/UnicodeDecodeError.
    - Parse ERR_* status and message into AFMCommandError.
    - Serialize whole commands with a non-blocking lock that raises
    AFMBusyError, and make disconnect() safe from another thread.
    - Clear the socket when the welcome read fails so reconnect works.
    - Reject non-ASCII and multi-line commands.
    - Cap the sweep timeout estimate and guard non-finite inputs.
    - Stop configuring the root logger from library import.
2026-09-10 FIX(cli): handle errors and invalid input without tracebacks
    - Catch AFMError (timeouts, disconnects, protocol errors) in raw
    command, single-command and script paths instead of only
    AFMCommandError.
    - Guard sweep step count against zero/non-finite values.
    - Validate data_show count and decode script files as UTF-8.
    - Configure logging in main() now that the client library does not.
2026-09-10 FIX(gui): unstick workers and shut down cleanly mid-measurement
    - Catch unexpected worker exceptions so Measure/Connect buttons are
    always re-enabled.
    - Disable every command control while a measurement runs and handle
    AFMBusyError on status refresh.
    - Abort in-flight reads and wait for workers in closeEvent.
    - Point the schematic dialog at the current client (or None) and stop
    refreshing when offline.
    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
2026-09-10 TEST(python): add client fake-server unit tests
    Cover welcome/connect cleanup, OK/ERR parsing, busy locking,
    spectrum byte-count and legacy framing, fragmented delivery,
    malformed and oversized headers, board status, and rp_deploy
    bitfile resolution. Runs with stdlib unittest and numpy only.
2026-09-10 TEST(python): add offscreen GUI smoke tests
    Exercise schematic construction, offline handling, peak detection and
    the full measure worker against the fake server. Skips automatically
    when PyQt6/pyqtgraph are not installed.
2026-09-10 FIX(client): handle cross-thread closes and busy shutdown
    - Translate an OSError from setblocking/settimeout after a concurrent
    disconnect() into AFMConnectionError instead of leaking it.
    - shutdown() now raises AFMBusyError and keeps the connection open when
    a measurement is in progress, so the caller can retry.
    - Document that ping() surfaces busy/connection errors and reference
    ServerConfig::MAX_SWEEP_POINTS next to the client constant.
    - TEST: closed socket and busy-shutdown cases.
2026-09-10 ADD(server): support Red Pitaya-only mode via --no-board
    - Add OperatingMode (FULL/RP_ONLY) and SYSTEM:MODE?, and report
    MODE= in SYSTEM:STATUS?.
    - --no-board skips electronic board creation and probing entirely;
    BOARD:* commands then fail with a clear RP-only error.
    - SYSTEM:INIT reports 'Board DISABLED (RP-only mode)'; measurements
    keep working and *RST preserves the configured mode.
    - Default FULL behavior (probe, fall back to NOT CONNECTED) unchanged.
    - Bump server version to 2.4.0.
    - TEST: option parsing, protocol parsing, handler behavior for both
    modes, and the disabled-mode board errors.
    [CommandHandler.cpp, Protocol.h, test_command_handler.cpp]
2026-09-10 ADD(client): surface Red Pitaya-only mode
    - afm_client: OperatingMode enum, get_mode() and MODE parsing in
    SystemStatus (older servers fall back to FULL).
    - GUI disables the board panel and routing schematic and shows an
    RP-only status instead of a red cross.
    - CLI prints the mode and explains unavailable board commands.
    - Schematic reports RP-only instead of hitting BOARD:STATUS?.
    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
2026-09-10 MOD(docs): document Red Pitaya-only operation
    Mark the analog board as optional and add a usage section for
    --no-board: signal on IN1, unavailable BOARD:* commands, SYSTEM:MODE?,
    and the automatic client-side board panel disable.
2026-09-10 FIX(gui): keep board controls consistent across measurement errors
    Separate board presence (board_available) from the transient global
    enable state so a measurement cycle no longer wipes it: _on_measure
    disables the controls, and a later error re-enables them without a
    status refresh.
    _set_controls_enabled and _update_board_controls now share
    _apply_board_enabled, which also disables the routing schematic button
    when no board is usable, matching the README.
    - Reset board_available only on disconnect, not on transient disables.
    - TEST: measure-error restore and status-refresh-while-disabled cases.
2026-09-10 FIX(client): close connection on read timeout
    A timed-out read left the socket open while the server was still computing the response, so the next command silently consumed the stale reply. For MEASURE:* that could return a valid-looking spectrum from the previous measurement (reproduced against the fake SCPI server).
    disconnect() on socket.timeout in _read_line and _read_exact so a late response can never be mistaken for the next command's result. Callers must reconnect after AFMTimeoutError.
    - TEST: timeout closes the socket and the next command raises instead of returning the stale payload.
2026-09-10 FIX(gui): sync connection UI after measurement error
    A read timeout closes the client socket, so the window must not keep showing the connected state. _on_measure_error now calls _update_connection_ui(self.client.is_connected): a server-side error keeps the controls enabled, while a lost connection falls back to the offline state and the next click reconnects.
    - TEST: connected and disconnected error paths update the buttons.
2026-09-10 MOD(hardware): map FPGA windows once and validate transfers
    Map the register page and the full 256 KB shared-BRAM window in initialize() and access them through m_regs/m_bram. The previous per-register mmap/munmap did a syscall pair per 4-byte sample (up to 131k syscalls for a 64k transfer), which dominated sweep latency.
    Transfers now surface failures that /dev/mem cannot report: clear the sticky STATUS flag before each load/read, fail when PS_ACCESS_DENIED is set, fail on a busy FSM instead of warning, and read count_measure back (a nonzero mismatch with the requested size is rejected; advisory until the RTL latches the final count).
    - startMeasurement rejects delays above 262143 (delay_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
2026-09-10 FIX(hardware): bound acquisition reads and harden init/load
    getAcquiredSignal read signal.size() words through the single 256 KB BRAM mapping with no upper bound, so an oversized vector would walk past the mapping (SIGSEGV). Reject sizes above MAX_SAMPLES like loadGenerationSignal already does.
    Move the sample-count, delay and acquired-count checks into the new HardwareLimits.h (mirroring DacCodec.h) so they can be unit-tested without /dev/mem. isCountConsistent treats a zero count as "unknown": the RTL clears it at completion and its 16-bit counter wraps at exactly 65536.
    Also tighten the contract: initialize() rejects a second call instead of leaking the fd and mappings, loadGenerationSi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
2026-09-10 TEST(hardware): cover hardware limits
    Boundary tests for the HardwareLimits validators used by RedPitayaHardware: sample counts 0/1/65536/65537, delays 0/1/262143/262144, and acquired-count consistency including the 16-bit wrap at 65536.
2026-09-10 ADD(ci): compile-check POSIX-only sources
    test_host excludes the POSIX-only sources (RedPitayaHardware, the UART driver, TCP server, hardware factories, server main and the OLED tool), so nothing compiled them in CI and the C++ hardware chan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
2026-09-10 ADD(cli): reconnect after lost connection
    A read timeout now closes the socket, which left the interactive shell without a way back: every follow-up command failed with "Not connected" until the process was restarted. Add 'connect [host] [port]', which replaces the client and reconnects, plus tests for the success, refused and non-numeric-port paths.
2026-09-10 FIX(gui): sync connection UI on command errors
    Only the measurement path reflected a timeout-induced disconnect. Add _sync_connection_ui() and call it from every other AFMError handler (init, status, mux, gain, board status and board reset) so the window falls back to the offline state instead of showing Disconnect on a dead socket.
2026-09-12 ADD(hardware): ADC input safety model and saturation detector
2026-09-12 ADD(server): ADC overdrive interlock with warn and allow replies
2026-09-12 ADD(clients): ADC loop command and protection warnings in python tools
2026-09-12 FIX(hardware): conservative gain fallbacks and structured board gain query
    [ElectronicBoardUART.cpp, IElectronicBoard.h, InputSafety.h]
2026-09-12 FIX(server): refresh ADC overdrive estimate lazily and harden loop command
    [CommandHandler.cpp, Protocol.h, test_command_handler.cpp]
2026-09-12 MOD(clients): clear stale ADC warnings and split gain WARN display
2026-09-12 FIX(server): value-initialize gain query buffers to fix UBSan bool load
    [CommandHandler.cpp]
2026-09-13 REF(cpp): deduplicate gain tables, decimation validation and handler guards
    - Single gain table in IElectronicBoard (label + factor) drives
    gainToString, gainFactor and new gainFromLabel; drop the duplicate
    table in BoardProtocol
    - HardwareLimits::isValidDecimation replaces duplicated range and
    power-of-2 checks in RedPitayaHardware and CommandHandler;
    ServerConfig MIN/MAX_DECIMATION alias the HardwareLimits constants
    - CommandHandler: _requireBoard and _validateChannel1Based replace the
    repeated guard pairs and 1-based channel range checks in all BOARD
    handlers
    - CommandHandler: extract _parseMeasTailArgs, _validateAmplitude,
    _validateNyquist, _trackExcitationAmplitude and _ap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
    [CommandHandler.cpp, IElectronicBoard.h, Protocol.h]
2026-09-13 FIX(cpp): review follow-ups for the dedup refactor
    - _handleBoardGain uses gainFromIndex instead of a raw static_cast so
    the valid-index knowledge lives in one place (range check kept for
    the explicit ERR_PARAM reply)
    - static_asserts pin c_GainTable size and order against MAX_GAIN_INDEX
    and the GainSetting enum values
    - gainToString rewritten in plain bounds-check form
    - _applyDecimation returns the sampling frequency and the sweep no
    longer recomputes it locally
    - _trackExcitationAmplitude moved after all validation: a rejected
    MEASURE command no longer clears the previous acquisition SAT state
    - boundary tests for HardwareLimits::isValidDecimation
    All 248 host tests pass.
    [CommandHandler.cpp, IElectronicBoard.h]
2026-10-10 ADD(board): routing query parsed from the board STATUS reply
    - BoardProtocol::parseRoutingStatus reads the "Routing:" section
    ("OUT<n> <- IN<m>" / "OUT<n> <- X") the same way parseGainStatus
    reads the gains; unreadable outputs are reported as invalid
    - IElectronicBoard::queryRouting exposes it as a structured query,
    implemented by ElectronicBoardUART and the mock
    Needed by the ADC input protection, which has to know which board input
    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
2026-10-10 FIX(server): refuse measurements that would overdrive the ADC input
    The monitor was designed as a measurement quality hint because
    InputSafety.h stated that the Red Pitaya input survives +/-30 V. That
    figure is the HV rating. On the LV (+/-1 V) jumper position, which is
    the only one used, Red Pitaya rates the input at 6 V absolute maximum
    and, above 1 kHz, at its full scale, while the board can deliver about
    +/-10.5 V. Overdrive is therefore treated as a protection matter.
    - InputSafety.h: corrected rating and rationale; the estimate is
    described as nominal, the return stage clips at the board rail like
    the drive stage, DAC full scale and the Red Pitaya link channels are
    named constan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
2026-10-10 ADD(clients): ADC protection override and persistent ADC state in python tools
    - client: SystemStatus.adc_protect (PROTECT=, None for servers older
    than 2.6.0), set_adc_protect / get_adc_protect, set_adc_loop_auto,
    and AFMCommandError.is_adc_overdrive to recognize a refused measurement
    - cli: adc_protect [on|off], adc_loop auto, protection state in status,
    and a hint on how to override when a measurement is refused
    - gui: "ADC Input" line in the status panel (OK / overdrive risk /
    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
2026-10-10 MOD(docs): document the ADC input protection
    - README: new section on the LV input limits, the automatic loop, the
    refusal and its override, the status fields and the limits of the
    estimate; BOARD:ADC:LOOP and BOARD:ADC:PROTECT added to the SCPI table
    - afm_server --help lists SYSTEM:MODE, BOARD:ADC:LOOP and
    BOARD:ADC:PROTECT
2026-10-10 ADD(server): declared sample gain for the ADC overdrive estimate
    The estimate assumed the AFM returns the excitation unchanged, so a
    weak return signal that needs a high return gain was always refused.
    - BOARD:ADC:SAMPLEGAIN <factor> (default 1, range 1e-6 to 1000) is the
    expected return / excitation ratio of the sample; it scales the
    predicted peak and the suggested gains and amplitude
    - Not applied when the excited input is routed straight to the ADC
    - Reported as SAMPLEGAIN= in SYSTEM:STATUS, reset by *RST
    9 new host tests, 286 pass.
2026-10-10 ADD(clients): sample gain setting in python tools
    - client: SystemStatus.adc_sample_gain, set_adc_sample_gain,
    get_adc_sample_gain
    - cli: adc_sample_gain [factor], shown in status
    - gui: "Sample gain" field in the board panel, synced from the server
    3 new tests, 80 pass.
2026-10-10 MOD(docs): document the sample gain
2026-10-10 FIX(server): sweep stop point and phase convention
    - A float step such as 0.1 kHz made the point count land just under an
    integer and dropped the stop frequency (100 points instead of 101).
    The count now has a relative tolerance and points are clamped to stop
    - The lock-in reported atan2(sin, cos), which is 90 deg minus the phase
    of the response. It now reports the phase relative to the sine
    excitation (negative = lag)
    - Tests assert magnitude, phase and frequency values of MEASURE:SWEEP
    and MEASURE:SINC, and that a rejected MEASURE keeps the SAT flag
    - Server version 2.7.0 (sweep phase values change)
    7 new host tests, 293 pass.
2026-10-17 ADD(python): hardware-in-the-loop check over SCPI
    Replaces the on-device tests removed in #1. With OUT1 looped back to IN1 (through the board at x1 or a direct cable in --no-board mode) it checks signal level and flatness, linear phase, every decimation, the sinc level against the sweep gain, the full 65536-sample depth, amplitude linearity (stale data) and repeatability. Unit tests run it against a simulated loop with injected faults.
2026-10-17 FIX(board): match replies to their command and bound each command
    A reply is accepted only after the echo of the command that was sent, and the UART input is flushed before each send, so a late reply of a timed-out command can no longer answer the next one. One deadline covers the whole reply and a reply is capped at 64 lines, so a board that keeps printing cannot hang the server. The STATUS block no longer starts with the '> STATUS' echo.
2026-10-17 MOD(server): frame BOARD:STATUS? with a line count
    The reply is now 'OK LINES <N>' followed by N lines, so the client no longer depends on the firmware footer line. The client still reads the unframed reply of servers before 2.8.0 and drops the echo line. Server version 2.8.0.
2026-10-17 MOD(server): log client socket options that fail to apply
    A failed timeout or keepalive option fell back silently to the one hour idle timeout.
2026-10-17 FIX(server): exit the process after SYSTEM:SHUTDOWN
    main() only waited for SIGINT or SIGTERM, so after SYSTEM:SHUTDOWN the process stayed alive with /dev/mem and the board UART open.
2026-10-17 ADD(server): cancel a sweep when the client leaves or the server stops
    The sweep checks between points whether the client closed the connection or the server is stopping, and returns ERR_ABORTED. A killed client no longer holds the DAC and the single client slot for minutes, and Ctrl+C no longer waits for the sweep. Version 2.9.0.
2026-10-17 MOD(client): sweep timeout from the decimation and TCP keepalive
    The sweep timeout was 2 s per point plus 30 s, 2.3 hours for 4096 points. It now follows the acquisition time (8192 samples at 125 MHz / decimation) plus 0.1 s per point: 12 minutes at most. Keepalive notices a dead link after about 25 s. Also: a failed connect closes its socket, an unknown server mode is UNKNOWN instead of FULL, and send_command reads OK LINES replies in full.
2026-10-17 MOD(cli): reconnect hint, Ctrl+C cancel, no board pre-check
    After a lost connection every command answered 'Not connected' with no hint. Ctrl+C during a measurement closes the connection. Board commands no longer send SYSTEM:STATUS? first: the server error says why the board is unusable.
2026-10-17 MOD(gui): control commands off the GUI thread, Cancel button, one schematic dialog
    Control commands ran on the GUI thread with the 10 s client timeout, so a silent server froze the window. They now run one at a time on a worker, the schematic dialog included. A lost connection in t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
2026-10-17 TEST(server): use NiceMock in the command handler fixture
    The plain mocks printed 668 uninteresting-call warnings per run, which buried real failures.
2026-10-17 MOD(server): refuse extra arguments and hex numbers, skip sweep points at 0 Hz
    Each command now declares its largest argument count; extra arguments return ERR_SYNTAX, so SYSTEM:MODE FULL is refused instead of answering OK with the unchanged mode. Numbers must be decimal. A sweep reaching below 0 Hz keeps its grid and skips those points instead of reporting a fake 0 Hz point. Lines are trimmed and the keyword may end with a tab. Error texts come from the limits, and MEASURE:SINC names the excitation band in its Nyquist error. Version 2.10.0.
2026-10-17 MOD(python): shared gain and decimation lists, firmware routing in the mock, SSH timeout
    The gain labels and decimations were repeated in the GUI and the CLI; they now come from afm_client. The schematic preview removed other routes of the same input, the firmware keeps them. rp_deploy w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
2026-10-17 FIX(board): help text matches the routing rule
    The firmware routes one input to several outputs, but HELP said one output only and a failed route reported 'Input already in use'. Takes effect on the next firmware build.
2026-10-17 FIX(deploy): do not sync local build outputs to the board
    The sync copied the ignored cpp/out/host folder (host test builds) to the Red Pitaya. Local files now follow the same build artifact rule as remote ones.
2026-10-17 FIX(deploy): remote output with non-ASCII characters no longer crashes the script
    --install-oled printed the systemctl status bullet and failed on a cp1252 console after a successful install.
2026-10-18 FIX(server): phases relative to the excitation, sweep ignores the input offset
    The acquisition starts one sample after the generation (single BRAM), so every phase carried a lead of 360 deg * f / fs. The server now asks for that delay explicitly and removes it. The sinc phase is also taken relative to the pulse, which sits at the centre of the record: odd FFT bins no longer come out 180 deg off. The sweep uses the sine fit, so a DC offset on the input no longer leaks into the low-frequency points, and it leaves out the samples taken after the excitation ended. Protocol version 2.11.0.
2026-10-18 FIX(gui): fit small screens, results no longer resize the window
    The sidebar scrolls instead of setting the window height (1000 px on a
    1440x900 screen), so Windows no longer squeezes the board buttons on top of
    each other. The result labels keep a fixed width and the ADC status wraps,
    so a result never widens the window. The first window size follows the
    screen.
2026-10-18 FIX(gui): sinc magnitude in volts, Q interpolated and bounded by the resolution
    The sinc magnitude is a per-bin FFT level, so the GUI showed a quartz at
    315 uV where a sweep reads tens of mV. It is now scaled to the amplitude a
    sine of the same setting gives (sinc_amplitude_scale, shared with the HIL
    check), so sinc and sweep read in the same volts.
    The -3 dB edges are interpolated between points. A band narrower than three
    frequency steps shows as a bound ("< 22.4 Hz", "> 6872") instead of a Q
    that only reflects the bin width.
2026-10-18 MOD(gui): foldable board panel, aligned panel fields
    Clicking the Board Configuration title folds the panel, so the measurement
    controls fit a laptop screen without scrolling. The choice is kept in the
    user settings. The title stays clickable while the board controls are
    disabled.
    Labels, check boxes and radio buttons no longer sit on a dark box, and all
    sidebar panels share one grid with equal label and field columns, so the
    fields line up and the labels have room.
